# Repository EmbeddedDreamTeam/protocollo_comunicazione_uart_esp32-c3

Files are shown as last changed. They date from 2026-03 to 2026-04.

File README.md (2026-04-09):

# Molecubes - Modular Robotic Arm

<div align="center">
Molecubes Logo
</div>

---

<div align="center">

           
</div>

---

## Table of Contents

<details>
  
- [Molecubes - Modular Robotic Arm](#molecubes---modular-robotic-arm)
  - [Table of Contents](#table-of-contents)
  - [Idea of the project](#idea-of-the-project)
  - [Requirements](#requirements)
    - [Hardware Requirements](#hardware-requirements)
    - [Software Requirements](#software-requirements)
  - [Getting Started](#getting-started)
    - [Setting up the Base Module](#setting-up-the-base-module)
    - [Setting up the Cube Modules](#setting-up-the-cube-modules)
    - [Setting up Wiring](#setting-up-wiring)
    - [Setting up ESP32 Software](#setting-up-esp32-software)
    - [Setting up Python Communication](#setting-up-python-communication)
  - [Project Layout](#project-layout)
  - [User guide](#user-guide)
  - [Team Members](#team-members)
  - [Resources](#resources)
  - [License](#license)

</details>

## Idea of the project 

The main idea of the Molecubes project is to build a modular robotic arm that utilizes a unique approach to movement through motor twisting. This design provides significantly more freedom of movement, allowing the arm to achieve various positions with different twists. The arm consists of interconnected cubes, each containing a servomotor, connected via magnetic connectors for easy assembly and reconfiguration.Thanks to the modular nature of the arm we can make use of differents attachment and cube layout that best suites a precise situation. 

The system is controlled by an ESP32-C3 microcontroller in the base module, with communication handled through Python scripts for user interaction and control.

## Requirements 

### Hardware Requirements 

- <u>**ESP32-C3**</u> microcontroller for the base module
- 3D printed housing for the base module
- Full set of cables (male-to-male, male-to-female)
- For each cube module:
  - 1x <u>**3D printed housing**</u>
  - 1x <u>**Servomotor**</u>
  - <u>**Set of cables**</u>
  - 2x <u>**Headed pin magnetic connectors**</u>

- 1x <u>**Breadboard**</u> (optional for prototyping)

<div style="display: flex; justify-content: space-between; align-items: center;">
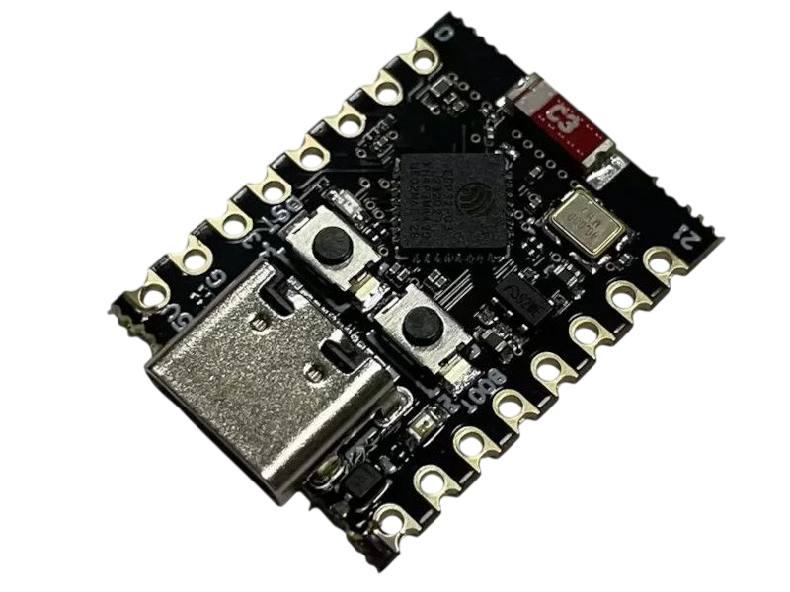
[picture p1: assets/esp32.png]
ESP32-S3
    
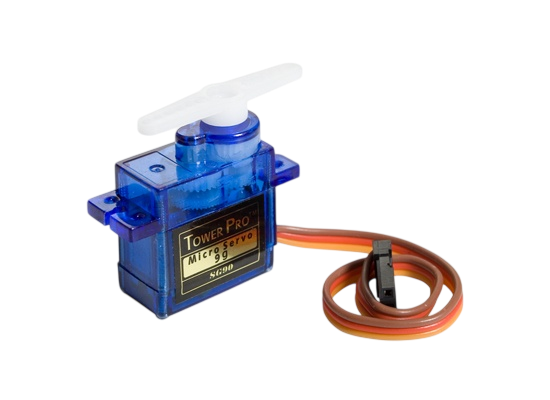
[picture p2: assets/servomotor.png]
Servomotor
    
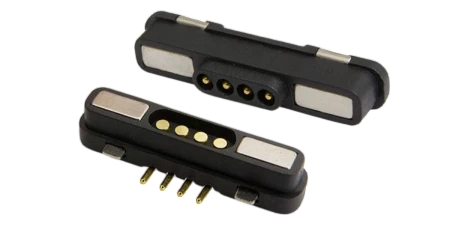
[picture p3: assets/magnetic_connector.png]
Magnetic Connector
    
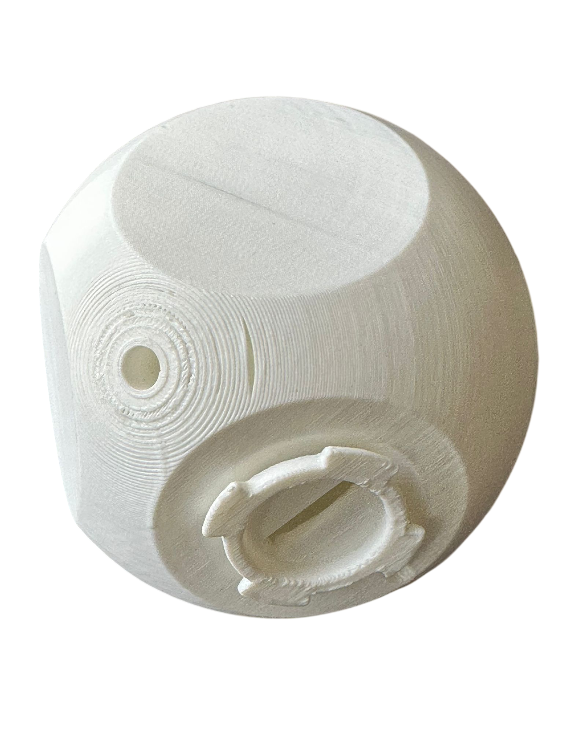
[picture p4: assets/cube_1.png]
Cube 1
    
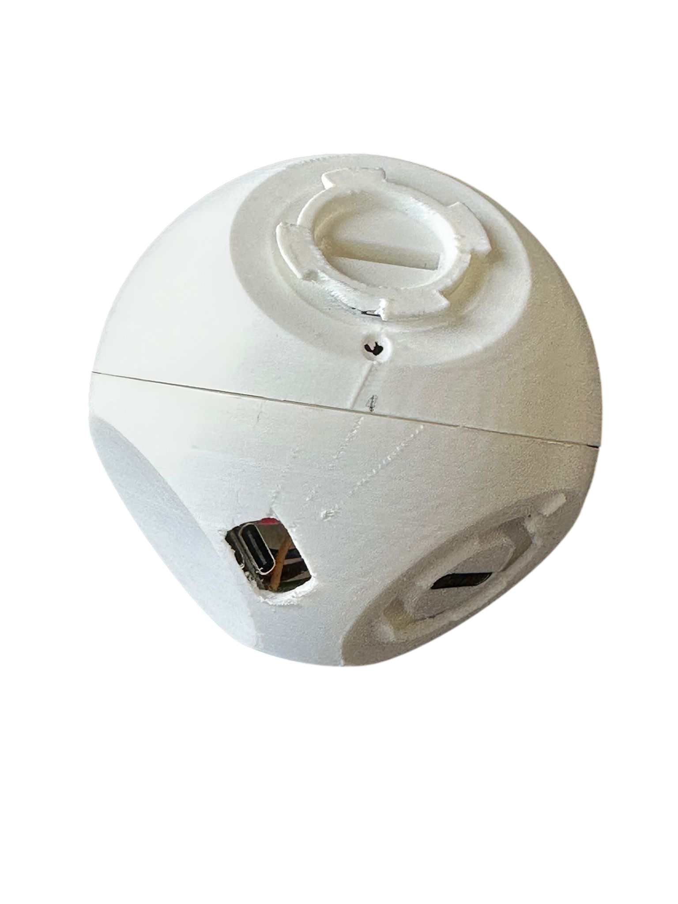
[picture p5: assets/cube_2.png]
Cube 2
    
</div>

### Software Requirements 

- [PlatformIO IDE](https://platformio.org/)
- Python IDE (e.g. [PyCharm](https://www.jetbrains.com/pycharm/), [VS Code](https://code.visualstudio.com/))

#### Setting Up Python 

To run this project, you need to have PlatformIO IDE and Python installed along with the required dependencies.

## Getting Started 

---

### Setting up the Base Module 

The project begins with the assembly of the base module:

1. **3D Print the Base Housing**: Print the base housing using PLA material.
2. **Install ESP32-C3 and servo motor**: Mount the ESP32-C3 microcontroller, servomotor and connectors inside the housing.
3. **Flash the base esp32 with the root code**: Run PlatformIO esp32-c3-root task to upload the firmware.
3. **Connect Power and Interfaces**: Ensure proper connections for power supply, do not power more than a cube with usb.

### Setting up the Cube Modules 

Each cube module requires the following assembly:

1. **3D Print the Cube Housing**: Print the cube housing using PLA material.
2. **Install Servomotor and ESP32-C3**: Mount the servomotor,ESP32-C3 and connectors inside the housing, ensuring proper alignment for twisting motion.
3. **Attach Magnetic Connectors**: Install the 2 headed pin magnetic connectors on opposite faces of the cube for modular connection.
4. **Wire the Components**: Connect the servomotor to the appropriate cables for power and signal transmission.

### Setting up Wiring 

---

The Molecubes system uses a **daisy-chain UART communication topology**:
- The **base module (ROOT)** is the primary master
- Each **cube module** acts as both a **SLAVE** to its predecessor and a **MASTER** to the next cube
- This allows commands to propagate through the chain: ROOT → Cube 1 → Cube 2 → Cube 3, etc.

#### Pin Configuration

```c
// ROOT Module (Base) - Only acts as MASTER
#define U_WITH_MASTER 0
#define FROM_MASTER_RX 10    // Receive data from Cube 1 on pin 10
#define TO_MASTER_TX 9       // Transmit data to Cube 1 on pin 9

// CUBE Module - Acts as both SLAVE and MASTER
// SLAVE Configuration (receives from previous module)
#define U_WITH_SLAVE 1
#define FROM_SLAVE_RX 2      // Receive data from previous module on pin 2
#define TO_SLAVE_TX 3        // Transmit data to previous module on pin 3

// MASTER Configuration (transmits to next module)
#define FROM_MASTER_RX 10    // Receive data from next cube on pin 10
#define TO_MASTER_TX 9       // Transmit data to next cube on pin 9
```

#### Communication Chain Diagram

```
Root (Master Only)
       ↓↑ (pins 9,10)
    Cube 1 (Slave ↓, Master ↑)
       ↓↑ (pins 3,2) ← (pins 9,10)
    Cube 2 (Slave ↓, Master ↑)
       ↓↑ (pins 3,2) ← (pins 9,10)
    Cube 3 (Slave ↓, Master ↑)
```

#### Wiring Steps

1. **Power Supply**: 
   - Connect the ESP32-C3 base to a stable power source (5V).
   - Ensure each cube module receives proper power through the magnetic connectors.
   - Do not power more than one cube via USB simultaneously to avoid power supply issues.

2. **Root Module (BASE) UART Connections**:
   - Pin 10 (FROM_MASTER_RX): Receives serial data from Cube 1's TO_SLAVE_TX
   - Pin 9 (TO_MASTER_TX): Transmits serial data to Cube 1's FROM_SLAVE_RX

3. **Cube Module UART Connections** (as Slave to previous module):
   - Pin 2 (FROM_SLAVE_RX): Receives serial data from the previous module (chained)
   - Pin 3 (TO_SLAVE_TX): Transmits serial data to the previous module (chained)

4. **Cube Module UART Connections** (as Master to next module):
   - Pin 10 (FROM_MASTER_RX): Receives serial data from the next cube (if connected)
   - Pin 9 (TO_MASTER_TX): Transmits serial data to the next cube (if connected)

5. **Module Connections**: 
   - Use the magnetic connectors to link cube modules in series to the base.
   - Connection pattern: Root TX (pin 9) → Cube 1 RX (pin 2), Root RX (pin 10) ← Cube 1 TX (pin 3)
   - Each subsequent cube follows the same pattern: Cube N TX (pin 3) → Cube N+1 RX (pin 2), Cube N RX (pin 10) ← Cube N+1 TX (pin 9)

6. **Servomotor Signal Cables**: 
   - Route signal cables from each servomotor to the appropriate GPIO pins on the ESP32-C3.
   - Ensure proper power delivery to servomotors through dedicated power lines.

### Setting up ESP32 Software 

---

To program the ESP32-C3, follow these steps:

1. **Install PlatformIO IDE**
   - Download and install PlatformIO IDE from the official website: [PlatformIO Download](https://platformio.org/platformio-ide).
   - Open the project in PlatformIO.

2. **Build and Upload**
   - For the base module, upload the `esp32-c3-root` configuration.
   - For cube modules, upload the `esp32-c3-devkitm-1` configuration.

#### Project Layout 

```
molecubes/
├── platformio.ini                    # PlatformIO configuration
├── src/
│   ├── CMakeLists.txt                # Build configuration for ESP32 targets
│   ├── esp32-c3/
│   │   └── main.cpp                  # Root firmware for ESP32-C3 base module
│   └── esp32-s3/
│       └── main.cpp                  # Optional ESP32-S3 target firmware
├── lib/
│   ├── cinematics/                   # Kinematic control and motion helpers
│   ├── uart_code/                    # UART communication and command handling
│   └── wifi_code/                    # WiFi initialization and network management
├── include/
│   ├── cinematics_header/            # Servo and motion headers
│   ├── uart_headers/                 # UART and protocol headers
│   └── wifi_headers/                 # WiFi and TCP server headers
├── python client/
│   ├── esp32_client.py               # Python communication script
│   └── requirements.txt              # Python dependencies
├── esp32-c3/                         # ESP32-C3-specific board configuration files
├── esp32-s3/                         # ESP32-S3 board configuration defaults
```

* **`platformio.ini`**: Project configuration for PlatformIO and build environments.
* **`src/esp32-c3/main.cpp`**: Main firmware for the ESP32-C3 base/root module.
* **`lib/`**: Contains source implementation for kinematics, UART, and WiFi modules.
* **`include/`**: Contains header declarations for the firmware modules in `lib/`.
* **`python client/`**: Python-side communication tools for controlling the arm.

## User guide

1. **Power Up the Root Module**: Connect power to the root ESP32-C3 module and wait for it to initialize.
2. **Connect to WiFi**: The root module creates a WiFi access point. Connect your computer to this WiFi network.
3. **Start Python Script**: Run the Python client script (`esp32_client.py`) to establish a connection with the root module.
4. **Control Modes**:
   - **Manual Mode**: Input specific parameters including angles, speed, acceleration, and jerk for precise control. While in manual mode, you can hot-swap cubes and various attachments without interrupting operation.
   - **Auto Mode**: Run predefined sequences that execute automatically, following programmed movement patterns.

## Team Members 

- **Marco Adami** — `marco.adami@studenti.unitn.it`
  - Major developer of the WiFi connectivity section
- **Matteo Ballardin** — `matteo.ballardin@studenti.unitn.it`
  - Minor developer of the WiFi connectivity section
  - Minor developer of kinematics controls
- **Mattia Pistollato** — `mattia.pistollato@studenti.unitn.it`
  - 3D modelling of the cubes
  - Hand construction of the cubes
  - Major developer of kinematics controls
- **Cesare Roversi** — `cesare.roversi@studenti.unitn.it`
  - Major developer of inter-cube connectivity

## Resources 

- YouTube: https://www.youtube.com/watch?v=YOUR_VIDEO_LINK
- Presentation: https://www.example.com/presentation-link

## License

This project is licensed under the MIT License - see the [LICENSE](LICENSE) file for details.

---

*For more information, please refer to the project documentation or contact the development team.*

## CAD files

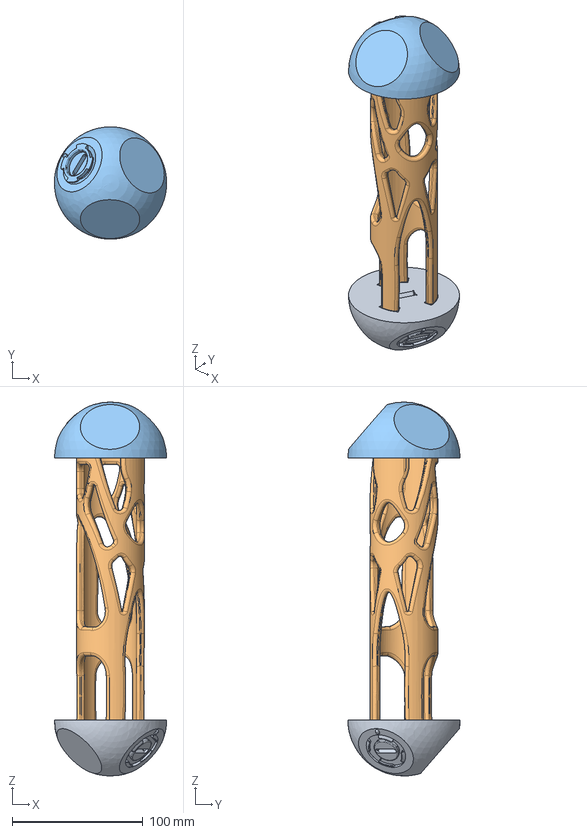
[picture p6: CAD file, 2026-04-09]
3d models/molecubes_arm.step
85.9 x 85.9 x 285.9 mm

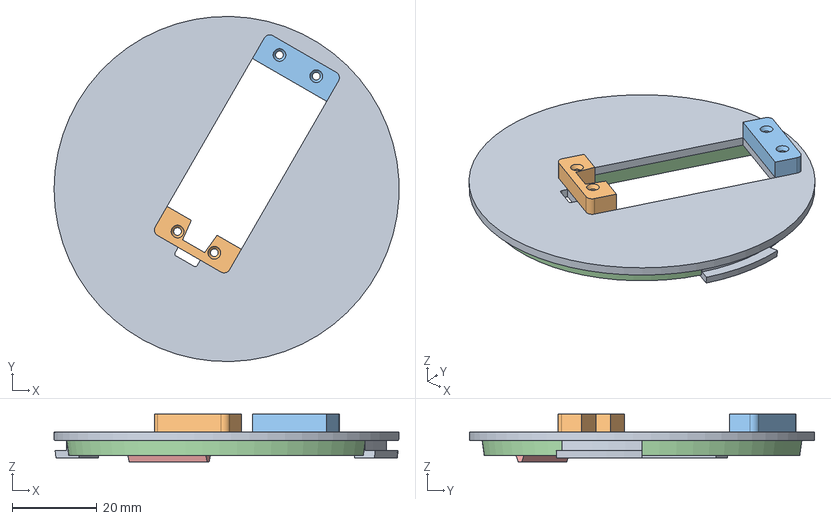
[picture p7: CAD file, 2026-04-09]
3d models/molecubes_cover.step
81.2 x 81.2 x 11.2 mm

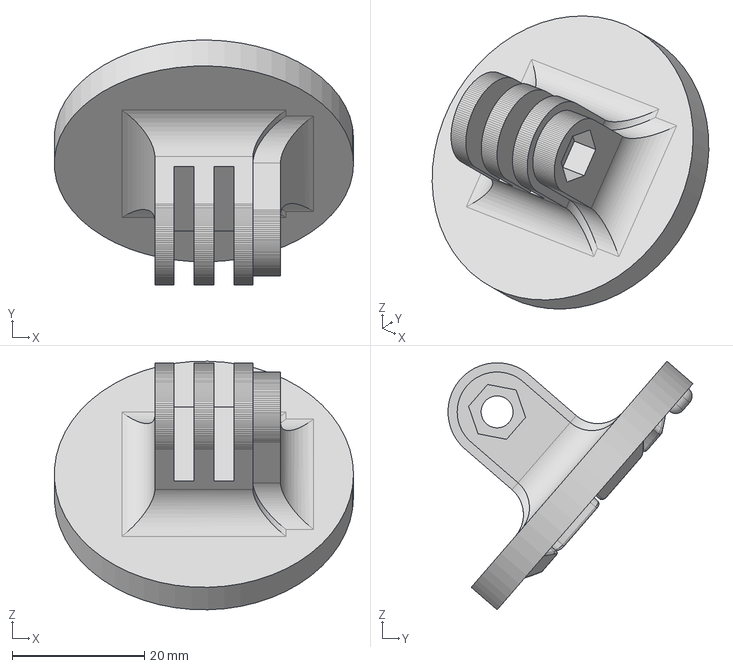
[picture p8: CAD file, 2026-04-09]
3d models/molecube gopro mount.step
45.3 x 37.1 x 37.6 mm

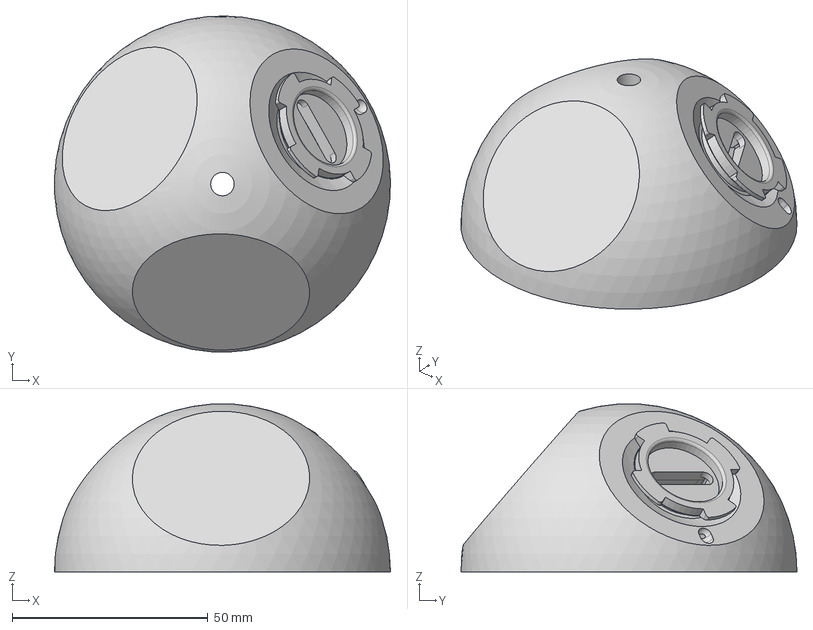
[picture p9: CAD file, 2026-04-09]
3d models/molecubes_top_half.step
85.9 x 85.9 x 42.8 mm

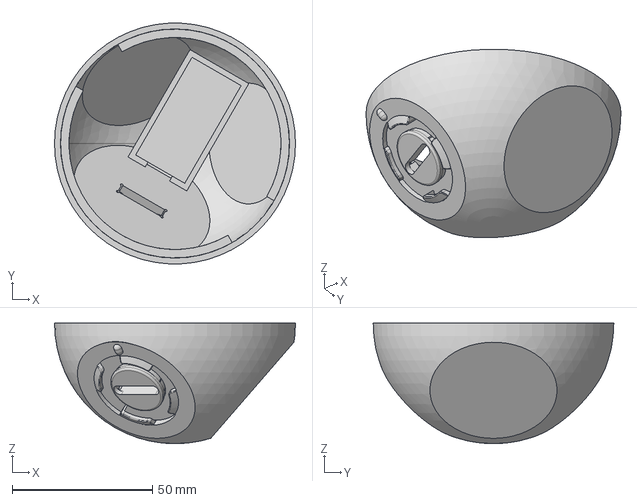
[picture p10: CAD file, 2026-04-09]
3d models/molecubes_bottom_half.step
85.9 x 85.8 x 43.0 mm

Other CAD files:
3d models/molecube gopro mount.stl
3d models/molecubes_bottom_half.stl
3d models/molecubes_cover.stl
3d models/molecubes_top_half.stl

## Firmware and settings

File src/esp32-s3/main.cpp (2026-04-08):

#pragma GCC optimize ("Os")
#include "servo_controller.h"
#include "utils_uart_comms.h"
#include "init_wifi.h"
#include "esp_mac.h"
#include "esp_system.h"
#include "esp_log.h"

void init_cube();
// void task_execute_servo(void *arg);

struct {
    uint8_t mac[6];
} molecube_data;

void init_cube() {
    uint8_t mac[6];
    esp_read_mac(mac, ESP_MAC_WIFI_STA);
    ESP_LOGI("CUBE_INIT", "MAC Address: %02X:%02X:%02X:%02X:%02X:%02X", mac[0], mac[1], mac[2], mac[3], mac[4], mac[5]);
    memcpy(molecube_data.mac, mac, 6); //copying the mac address byte to byte to the molecube_data struct
}

void handle_movement_ack(Msg* msg){
    //TODO complete this function, send the ack to the ui?
}

// Task: receive Msg* from the higher-level UART queue and translate into
// servo controller commands by calling move_servo_speed()
// this is needed beacause also the master has a servo

void task_execute_servo(void *arg) {
    (void)arg;
    extern QueueHandle_t h_queue_servo; // declared in utils_uart_comms.h / GLOBAL_VARS.cpp

    while (1) {
        Msg *msg = nullptr;
        if (xQueueReceive(h_queue_servo, &msg, portMAX_DELAY) == pdTRUE) {
            ESP_LOGI("EXEC_SERVO", "Received servo message, speed=%.3f, acc=%.3f, jerk=%.3f", msg->payload.payload_servo.speed, msg->payload.payload_servo.acceleration, msg->payload.payload_servo.jerk);
            if (msg) {
                float radians = msg->payload.payload_servo.radians;
                float speed = msg->payload.payload_servo.speed;
                float acc = msg->payload.payload_servo.acceleration;
                float jerk = msg->payload.payload_servo.jerk;
                esp_err_t err = move_servo_speed(radians, speed, acc, jerk);
                if (err != ESP_OK) {
                    ESP_LOGW("EXEC_SERVO", "move_servo_speed failed: %d", err);
                }
                delete msg; // free message allocated by UART layer
            }
        }
    }
}

extern "C" void app_main() {
    // Print reset reason early to determine if the board was reset or app_main returned
    esp_reset_reason_t reason = esp_reset_reason();
    const char* reason_str;
    switch(reason){
        case ESP_RST_UNKNOWN: reason_str = "UNKNOWN"; break;
        case ESP_RST_POWERON: reason_str = "POWERON"; break;
        case ESP_RST_EXT: reason_str = "EXTERNAL_RESET"; break;
        case ESP_RST_SW: reason_str = "SOFTWARE_RESET"; break;
        case ESP_RST_PANIC: reason_str = "PANIC"; break;
        case ESP_RST_INT_WDT: reason_str = "INT_WDT"; break;
        case ESP_RST_TASK_WDT: reason_str = "TASK_WDT"; break;
        case ESP_RST_WDT: reason_str = "WDT"; break;
        case ESP_RST_DEEPSLEEP: reason_str = "DEEPSLEEP"; break;
        case ESP_RST_BROWNOUT: reason_str = "BROWNOUT"; break;
        case ESP_RST_SDIO: reason_str = "SDIO"; break;
        default: reason_str = "OTHER"; break;
    }
    ESP_LOGI("BOOT", "Reset reason: %d (%s)", reason, reason_str);

    //initializing wifi, uart comms, cube data (mac address) and servo controller
    init_wifi();
    init_uart_comms();
    init_cube();
    servo_init();

    // create and start the task that listens for servo messages coming from
    // the UART/protocol layer and forwards movement commands to the
    // servo controller (move_servo_speed)
    xTaskCreate(
        task_execute_servo,
        "ExecServoTask",
        3072,
        NULL,
        2,
        NULL
    );

}

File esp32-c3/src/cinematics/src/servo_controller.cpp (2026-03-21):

#include "servo_controller.h"
#include <freertos/queue.h>

TaskHandle_t xTaskHandle = NULL;
static QueueHandle_t xServoQueue = NULL; //queue handler

// single definition of servo_data (shared across translation units)
ServoData servo_data = {
    .duty_res = 0,                // will be set by servo_timer_init()
    .gpio = 3,
    .sgnl_min_duty = 500,
    .sgnl_max_duty = 2500,
    .min_pos = (float)(-30.5/36.0*M_PI),
    .max_pos = (float)( 30.5/36.0*M_PI),
    .current_pos = std::atomic<float>(0.0f),
    .max_speed = 5.2f
};

void servo_timer_init();
void move_servo_speed_task(void * pvParameters);
void send_movement_ack(float rad);

void send_movement_ack(float rad){
    //TODO
}

void servo_timer_init(){
    servo_data.duty_res =ledc_find_suitable_duty_resolution(80000000, 50);//auto clock freq of 80MHz and timer freq of 50Hz, the most common servo frequency
    ledc_timer_config_t timer_config ={
        .speed_mode=LEDC_LOW_SPEED_MODE, //low speed is sufficient for controlling a servo
        .duty_resolution = static_cast<ledc_timer_bit_t>(servo_data.duty_res),
        .timer_num=LEDC_TIMER_0, //timer number
        .freq_hz=50,
        .clk_cfg=LEDC_AUTO_CLK,
        .deconfigure=false,
    };
    ledc_timer_config(&timer_config);
    ledc_channel_config_t channel_config={
        .gpio_num=servo_data.gpio, //signal pin of the servo
        .speed_mode=LEDC_LOW_SPEED_MODE,
        .channel=LEDC_CHANNEL_0,
        .intr_type=LEDC_INTR_DISABLE,
        .timer_sel=LEDC_TIMER_0,
        .duty=0,
        .hpoint=0,
    };
    ledc_channel_config(&channel_config);
}
//converting degrees to radians
float rad_from_deg(int32_t degrees){
    return ((float)degrees/360.0 * 2*M_PI);
}

//this type of servo has a frequency of 50Hz and, considering the trimming zone they accept a signal that
// ranges from ~351ms to ~2640 ms  that corresponde to a range of motion of nearly ~309 degrees 
/// NOTE this function isn't meant to be used alone, it is used by the move_servo_speed function to set the position of the servo, if you want to set the position directly use move_servo_speed with speed=1.0f
esp_err_t set_servo_pos(float rad){
    if (rad>=servo_data.min_pos && rad<=servo_data.max_pos){
        ESP_LOGI("SERVO_API", "Posizione impostata: %.2f rad", rad);
        double mid_point=servo_data.sgnl_min_duty+(servo_data.sgnl_max_duty-servo_data.sgnl_min_duty)/2.0;
        //double time= mid_point+rad/servo_data.max_pos*(servo_data.sgnl_max_duty-servo_data.sgnl_min_duty)/2.0; //calculating the signal time
        double time= mid_point+rad/(1.5*M_PI)*(servo_data.sgnl_max_duty-servo_data.sgnl_min_duty); //calculating the signal time
        uint32_t max_duty = (1 << servo_data.duty_res);
        uint32_t duty= (uint32_t)(time/20000.0*max_duty); //fraction of the period in micro-seconds
        ledc_set_duty(
            LEDC_LOW_SPEED_MODE,
            LEDC_CHANNEL_0,
            duty
        );
        ledc_update_duty(LEDC_LOW_SPEED_MODE, LEDC_CHANNEL_0);
        // Update the logical current position (this is the commanded position,
        // not a physical feedback sample). Use atomic store for clarity.
        servo_data.current_pos.store(rad);
        return ESP_OK;
    }
    else{
        return ESP_ERR_INVALID_ARG;
    }

}

void move_servo_speed_task(void * pvParameters) {
    ServoTaskParams cmd;
    float current_rad = servo_data.current_pos.load();
    
    TickType_t xLastWakeTime;
    const TickType_t xFrequency = pdMS_TO_TICKS(20);

    while (1) {
        if (xQueueReceive(xServoQueue, &cmd, portMAX_DELAY)) {
            
            // initializing time: count of ticks since vTaskStartScheduler was called
            xLastWakeTime = xTaskGetTickCount();
            TickType_t xPreviousFrameTick = xLastWakeTime;

            while (fabs(current_rad - cmd.target_rad) > 0.005f) {
                // new commands check
                ServoTaskParams next_cmd;
                if (xQueueReceive(xServoQueue, &next_cmd, 0) == pdTRUE) {
                    cmd = next_cmd;
                }

                // calculating real dt (effective time elapsed)
                TickType_t xCurrentTick = xTaskGetTickCount();
                // calculating real time elapsed in seconds
                float dt = (float)(xCurrentTick - xPreviousFrameTick) * portTICK_PERIOD_MS / 1000.0f;
                xPreviousFrameTick = xCurrentTick;

                // step based on real time elapsed
                float step = cmd.speed * dt; 
                
                if (current_rad < cmd.target_rad) {
                    current_rad += step;
                    if (current_rad > cmd.target_rad) current_rad = cmd.target_rad;
                } else {
                    current_rad -= step;
                    if (current_rad < cmd.target_rad) current_rad = cmd.target_rad;
                }

                set_servo_pos(current_rad);

                // periodically waking this function a xFrequency rate
                vTaskDelayUntil(&xLastWakeTime, xFrequency);
            }
        }
    }
}


esp_err_t move_servo_speed(float rad, float speed){
    if (xServoQueue == NULL) {
        //ESP_LOGE("SERVO_API", "Errore: Coda non inizializzata!");
        return ESP_ERR_INVALID_STATE;
    }

    ServoTaskParams params;
    params.target_rad = rad;
    params.speed = speed>servo_data.max_speed?servo_data.max_speed:speed;
    // if the queue is full, we drop the oldest command to make room for the new one, ensuring that the servo always moves towards the most recent target position
    //ensuring reactivity
    if (xQueueSend(xServoQueue, &params, 0) != pdPASS) {
        ServoTaskParams dropped;
        xQueueReceive(xServoQueue, &dropped, 0);
        // trying to send the new command again after dropping the oldest one
        if (xQueueSend(xServoQueue, &params, 0) != pdPASS) {
            return ESP_ERR_INVALID_STATE;
        }
    }

    return ESP_OK;
}


void servo_init(){
    servo_timer_init();

    // ensure logical current position has a known value before task start
    servo_data.current_pos.store(0.1f);

    // creating the queue with the designed lenght
    xServoQueue = xQueueCreate(SERVO_QUEUE_LEN, sizeof(ServoTaskParams));

    // creating the persistent task
    xTaskCreate(
        move_servo_speed_task,
        "ServoMotorTask",
        3072, // Stack size
        NULL, //parameters
        1,
        &xTaskHandle
    );
    
    move_servo_speed(0.0f, 1.0f);
    vTaskDelay(pdMS_TO_TICKS(1000));
}

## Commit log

2026-02-23 pulito la logica di handshake type hello
2026-02-23 prima di far danni
2026-02-24 changed led functions, tested startup handshake
2026-03-04 fixed uart configuration
2026-03-10 worked on handshake, report logic needs to be fixed
    [init_communication.cpp]
2026-03-12 pass wifi payload to uart
2026-03-12 fixed hadle_report, general tweaks
    [init_communication.cpp]
2026-03-12 base implementation of servo control
2026-03-12 refactored servo pos function
2026-03-13 base implementation of servo control api
2026-03-14 fixed servo control time precision
    [servo_controller.cpp, tests.cpp]
2026-03-15 minor fixes and added project for cubes
    [main.cpp, servo_controller.cpp, tests.cpp]
2026-03-15 added master project
    [default_16MB.csv]
2026-03-21 refactored repo structure
    [default_16MB.csv]
2026-03-22 code cleanup and bug fix
    [main.cpp, servo_controller.cpp, tests.cpp]
2026-03-22 implemented servo ack function
2026-03-26 first modifications, seems to work
    [partitions.csv]
2026-03-27 complete refactor in one single platformio project
    [default_16MB.csv]
2026-03-27 bug fixes, now a cube sends a report only if it knows its master
    [main.cpp]
2026-03-28 commit before adding SHOW_UART_COMMS_LOGS guards to all prints
2026-04-01 Remove const number of servos
2026-04-02 added protection for servo deadzone
2026-04-02 updated servo cinematic with backlash and deadzone compensation
2026-04-03 updated backlash compensation and uart timing
2026-04-08 fixed bug in handling uart message
    [main.cpp]
2026-04-09 added 3d models and servo datasheet
    [molecube gopro mount.step, molecube gopro mount.stl, molecubes_arm.step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]
